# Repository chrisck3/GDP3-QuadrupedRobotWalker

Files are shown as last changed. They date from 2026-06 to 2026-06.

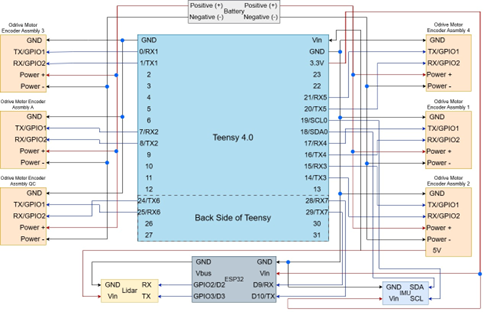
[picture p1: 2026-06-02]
Electronics Architecture/teensy_odrive_ASSY.png

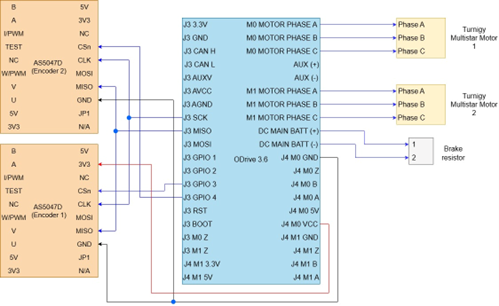
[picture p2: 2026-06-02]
Electronics Architecture/odrive_ASSY.png

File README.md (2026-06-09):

# MORPH — Modular Quadrupedal Robot Platform

**FEEG6013 Group Design Project, University of Southampton, 2025/26**

MORPH is an open-source quadrupedal robot built as a research and inspection platform. This repository hosts the full design package for the project: CAD, mechanical and electrical documentation, firmware for both the on-board controller and the wireless controller, the gait-generation GUI, and the supporting test and calibration material.

This year's project did not start from scratch. The mechanical chassis and the original Teensy gait code were inherited from a previous group's GDP. When we picked it up, the platform was not running. The aim for this iteration was to reactivate it, identify where it was falling short for real research and inspection use, and design, manufacture, and test the upgrades that would make it a credible open-source alternative to the commercial quadrupeds.

The robot now walks reliably on flat ground and slopes up to 12.5 degrees, stays statically stable up to 30 degrees, detects obstacles with LiDAR and stops before hitting them, and is driven from a phone over WiFi. What we did not finish, and what would be sensible next steps, is documented.

Although our robot is called MORPH, it should have been called Murphy, after the Murphy's Law. As the Murphy's law state, "Anything that can go wrong will go wrong", and with our robot that was definitely true during testing days!

<p align="center">
  
</p>


## What's new in this iteration

The mechanical core is iterated rather than rebuilt. The electronics, sensing, control, and software stack are mostly new. A short summary of the changes:

**Mechanical**

* Topology-optimised PLA leg structures (40% infill), validated by FEA, replacing the original plywood legs that were responsible for over 5% positional error.
* Custom AS40 silicone feet, cast in-house, with a measured static friction coefficient of around 1.15 against the design target surfaces.
* Adjustable leg-housing clasp with continuous variable tension, removing the slack and fatigue cracking that the original press-fit clasp suffered from.

**Electronics**

* Bespoke soldered protoboard with JST-XH connectors and header pins. Replaces the inherited breadboard and hot-glued wiring that was failing under vibration.
* BNO055 IMU mounted at the centre of mass for pitch and roll sensing.
* RPLidar A1 M8 mounted on top for 360-degree obstacle detection.
* Arduino Nano ESP32 added alongside the Teensy 4.0 for WiFi communication and to run the LiDAR safety stop loop.

**Software and sensing**

* Browser-based wireless controller served by the ESP32. Replaces the broken Bluetooth module on the inherited platform. MAC whitelist for access control.
* IMU sensor-fusion pipeline using a Kalman filter, plus a Periodic Disturbance Cancellation algorithm to remove the gait-induced body oscillation from the orientation signal. Lets the robot tell true terrain slope apart from its own walking wobble.
* Slope-responsive body levelling. The cleaned IMU pitch and roll are used to adjust individual leg heights so the body stays level on an incline.
* LiDAR cluster-detection algorithm that triggers an automatic stop before an obstacle, with debouncing across full sweeps to avoid twitching.
* Refactored, modular Arduino codebase with calibration tooling, structured to be readable by the next group rather than be a single 1500-line `.ino`.

## Hardware at a glance

|Subsystem|Part|Role|
|-|-|-|
|Main controller|Teensy 4.0|Runs the gait, kinematics, IMU fusion, and ODrive comms.|
|Wireless and safety|Arduino Nano ESP32|WiFi web server, LiDAR polling and obstacle stop.|
|Motor drivers|6x ODrive (v0.5.x)|Drive 12 BLDC motors over UART.|
|Actuation|12x BLDC motors with herringbone and worm-wheel gear reduction|Hip, knee, and shoulder for each of four legs.|
|Inertial sensing|Adafruit BNO055|Body pitch and roll for slope detection.|
|Obstacle sensing|Slamtec RPLidar A1 M8|360-degree 2D scan, drives the auto-stop.|
|Operator interface|Any phone, tablet, or laptop with a browser|Connects to the ESP32's hosted web page over local WiFi.|

Targets the platform was designed to and (within limits) achieved: 19 kg total mass, 5 kg additional payload, 0.25 m/s locomotion speed, 60 mm step length, 10% positional uncertainty benchmarked against the ANYmal platform.

## Getting started

The full assembly, calibration, and bring-up procedure is in repository. 

1. Open the assembly in Solidworks if you want to review or modify the mechanical design.
2. Wire the electronics per the wiring diagram. The protoboard is the central distribution point.
3. Calibrate the six ODrives one at a time using their own tools. The firmware tunes gains and limits on top but assumes the motor configuration is already valid.
4. Flash the Teensy firmware and the ESP32 firmware located on the repo. Each has its own README with the dependencies and bring-up steps.
5. Run the IMU calibration routine once on first power-up. Offsets are saved to EEPROM and reloaded automatically afterwards.
6. On the ESP32 serial monitor, note the printed IP address. Open it in a browser on a whitelisted device and the controller page loads.

## Group members (2025/26)

|Name|Primary contribution areas|
|-|-|
|James Over|Project lead, mechanical design, legs design, ODrive Calibration|
|Antoine Khoury|Mechanical design, Market Analysis, kinematics, ODrive Calibration|
|Nikolas Roussos|Wireless Communication, Software Lead, IMU filtering, Stakeholder Analysis|
|Christos Karayiannis|Mechanical design, foot design and manufacturing, testing|
|Antonin Develay|CAD Lead, Clasp and Leg Design|
|Andreas Savvidis|IMU Lead, lab testing|

## Acknowledgements

* **Dr. Thomas Bull** — primary supervisor, for guidance throughout the project.
* **Prof. Suleiman Sharkh** — co-supervisor, for technical advice on the motor drive and electronics side.
* **Paul Leggett** — for technical support and access to the mechatronics lab.

## Limitations and recommended future work

Some things we did not finish, and a few that we'd genuinely change if doing this again. Worth knowing before you build on the project:

* **Trot gait is not validated.** The trot gait table exists in the firmware and the robot can be made to trot in a controlled setting, but the dynamic stability has not been characterised. The default and tested gait is the crawl.
* **Weight-shift is implemented but disabled.** A separate weight-shift gait table is in `structdef.h` with the gain set to zero. It was never finished or tuned.
* **The Fourier and binned-angle terrain estimators in the IMU code are experimental.** The notch filter is the working production path. The Fourier path is left in for future work and currently uses placeholder coefficients.
* **The mechanical clasp design is improved but not perfect.** Long-duration fatigue testing was not in scope. Inspect periodically.
* **Outdoor LiDAR exposure.** The RPLidar A1 is vulnerable to direct sunlight. A simple optical shield is sketched in CAD but not manufactured.
* **Autonomy is limited to obstacle stopping.** There is no path planning or SLAM. The LiDAR data and ESP32 are capable of running this, and the framework is in place to extend in that direction.

If you take this further, the firmware READMEs are the right place to start.

## License

Open-source for academic and non-commercial use.

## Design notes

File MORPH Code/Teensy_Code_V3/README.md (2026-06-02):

# MQRPII Quadruped Firmware (Teensy 4.0)

Firmware for a four-legged walking robot, running on a Teensy 4.0. It drives 12 motors through six ODrive controllers, walks under WiFi command, and uses a BNO055 IMU to keep the body level on sloped ground.

This was part of a Group Design Project at the University of Southampton. I'm putting it up open-source so the next person who picks up a quadruped like this doesn't have to start from scratch. The code works and the robot walks, but it is research firmware, not a polished product. There are bits that are tuned and proven on the rig, and bits that are still placeholders waiting for someone to finish them. We've tried to be honest about which is which throughout, both here and in the comments.

## What it does

* Walks forward, backward, left, right, and yaws on the spot, commanded over WiFi.
* Converts foot position targets into ODrive encoder commands through a closed-form 2-link inverse kinematic model.
* Reads body pitch and roll from a BNO055 (Kalman-filtered) and adjusts individual leg heights so the body stays level on a slope.
* Stops on command, including a zero-packet stop intended for a LiDAR obstacle trigger.

The default gait is a 16-phase crawl (one leg at a time). A trot gait is included in the source but commented out, with instructions for switching.

## Hardware

| Teensy 4.0 : Main controller. Uses six hardware serial ports (Serial1-Serial6) for the ODrives and Serial7 for WiFi. |
| 6x ODrive (v0.5.x):| Driven over ASCII UART at 115200 baud. Four control a leg each (hip + knee); two are shoulder drives that each serve two legs. |
| 12x BLDC motors : Two per leg (hip, knee) plus shoulder abduction. |
| BNO055 IMU : On I2C (address 0x28). Used for slope detection. |
| ESP (WiFi link) : Sends the 3-value control packet to the Teensy. |

### Leg and ODrive mapping

The leg index convention is used everywhere in the code, so it's worth stating up front:

```
0 = FR (front right)
1 = BL (back left)
2 = FL (front left)
3 = BR (back right)
```

The mapping lives in `pos\_est()` and `actuate()` in `odrv\_rw\_functions.ino`. If you rewire anything, that is the single place you have to get right, or a leg will move on the wrong axis.

## Code structure

This is an Arduino multi-tab sketch. All the `.ino` files compile together as one program alongside the main `Teensy\_Code\_V2\_9\_4.ino`.

|File|What's in it|
|-|-|
|`Teensy\_Code\_V2\_9\_4.ino`|Main sketch. Setup, the WiFi packet state machine, the command mapping, and the main gait loop.|
|`structdef.h`|The gait tables. Pre-computed foot trajectories for the crawl gait (and a commented-out trot gait), phase by phase.|
|`matrix\_kinematics.ino`|Inverse kinematics. Turns x/y/z foot targets into ODrive encoder turns. Also builds the per-phase gait matrix in `create\_mat()`.|
|`odrv\_rw\_functions.ino`|Higher-level ODrive routines: set state, set input mode, read positions, actuate all 12 axes, push tuning gains.|
|`odrv\_dual\_axis\_ctrl\_Func.ino`|Low-level ODrive ASCII command wrappers (read/write a single axis).|
|`wifi\_func.ino`|Builds and sends the framed response packet back to the ESP.|
|`imu\_func.ino`|BNO055 setup and the per-loop IMU read, Kalman filtering, axis remapping, and gait-wobble removal.|
|`imu\_notch\_filter.ino`|Cascaded IIR notch filters that strip the gait oscillation out of the IMU signal so only real terrain tilt is left.|
|`imu\_calibration.h` / `.cpp`|Save and restore BNO055 calibration offsets to EEPROM.|
|`body\_level.ino`|Takes the cleaned terrain pitch/roll and works out how much to raise or lower each leg to keep the body level.|

## How it works

### Walking

The robot walks by stepping through a fixed table of foot positions (`structdef.h`). Each of the 16 phases gives every foot a target offset, made up of a vertical lift arc plus forward/back, lateral, and yaw components. The WiFi command scales those components: forward speed scales the FB table, strafe scales LR, turning scales RT. `create\_mat()` sums them, `kinematics\_mat()` converts the result to encoder positions, and an interpolation step ramps the motors smoothly between phases.

A phase only advances once all 12 interpolations have finished, so the gait timing follows the slowest joint rather than a fixed clock. The loop timer also scales with commanded speed, so a faster command means a faster cycle.

### Staying level on a slope

The IMU gives body pitch and roll, but walking itself rocks the body, so the raw signal is a mix of real slope and self-induced wobble. The firmware deals with this in two stages. `imu\_notch\_filter.ino` notches out the gait frequency and its second harmonic, leaving a cleaner terrain estimate. `body\_level.ino` then converts that pitch and roll into a height correction for each foot and feeds it into `hleg\[]`, the per-leg standing height the kinematics uses.

The slope correction is an integrator with memory, not a simple proportional adjustment. The reasoning behind that (and why a naive version caused the body to snap back and oscillate) is written out in the header comment of `body\_level.ino`. If you're going to touch the levelling, read that first.

### Communication

The ESP sends an 8-byte frame: `0xAA 0x55` header, six payload bytes (three big-endian int16 values), and a one-byte checksum. The Teensy parses it with a small state machine in the main loop, maps the three values to movement commands, and sends a framed acknowledgement back. An all-zero packet is treated as a stop, which is how the LiDAR obstacle trigger is meant to halt the robot.

## Getting it running

1. Install the Arduino IDE, and the libraries below (The RPLiDAR library is slightly modified).
2. Wire the six ODrives to Serial1-Serial6 and the WiFi module to Serial7. Check the leg mapping in `odrv\_rw\_functions.ino` matches your wiring.
3. Calibrate and tune your ODrives first using ODrive's own tools. This firmware assumes the motors are already configured and only pushes gains and limits on top.
4. Open `Teensy\_Code\_V2\_9\_4.ino` (it pulls in the other tabs automatically) and flash it.
5. On the first run, watch the serial monitor at startup. It prints the initial leg positions and flags an offset error if any axis reads zero, which usually means an ODrive isn't responding.

### Dependencies

* `ODriveUART` (ODrive v0.5.x ASCII interface)
* `Adafruit\_BNO055` and `Adafruit\_Sensor`
* `Kalman` by TKJ Electronics (https://github.com/TKJElectronics/KalmanFilter)
* `Ramp`
* `SerialTransfer`

## Things to know before you trust it

I'd rather you hit these in the README than discover them mid-test:

* **The IMU mounting offsets are hand-measured.** The trim values in `imu\_func.ino` correct for how the BNO055 sits on this chassis. On a different build they will be wrong. If the robot thinks it's tilted while sitting on a flat floor, that's the first thing to adjust.
* **The gait-wobble compensation is not finished.** The notch filter is the working path for removing wobble; the Fourier and bin methods are earlier experiments left in for reference. Don't expect the Fourier terrain estimate to mean anything until those coefficients are fitted to real logged data. The how-to-tune notes are in the comments.
* **`actuate2()` uses hardcoded encoder positions.** These are the measured home positions for this specific robot, found by hand which are 1/4 turn from the legs compressed limits. They are not general. If your assembly differs, these numbers will send the legs to the wrong place.
* **ODrive input mode numbers.** The code sets input mode 5 for trajectory control. Note that the surrounding comments occasionally call this TRAP\_TRAJ; check the mode against your ODrive firmware version, as the numbering matters and the comment may not match.

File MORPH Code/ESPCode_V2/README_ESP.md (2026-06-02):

# MQRPII ESP32 Controller and LiDAR Safety Stop

## What it does

- Hosts an HTTP server on the local WiFi network that serves a phone-friendly directional control page (forward, back, left, right, stop).
- Translates button presses into 8-byte binary packets and sends them to the Teensy over a UART link.
- Listens for the Teensy's acknowledgement packets on the same link and prints them to the serial monitor (for debugging).
- Polls an RPLidar continuously, runs a cluster-detection algorithm on the points, and overrides any forward command with a STOP if it sees an obstacle in the danger zone.
- Locks the controller to a MAC address whitelist so a random device on the same WiFi can't drive the robot.

## Hardware

| Part | Notes |
|---|---|
| Arduino Nano ESP32 | The main controller. Uses Serial1 for the LiDAR, Serial2 for the Teensy, USB Serial for the debug monitor. |
| RPLidar A1 | 360-degree 2D LiDAR. Mounted on top of the robot pointing forward. The 0-degree angle direction matters and is set by the physical mount. |
| Teensy 4.0  | Receives the binary motion command and runs the gait. |
| Phone, tablet, or laptop | Anything with a browser on the same WiFi network. |

### Pin map

```
ESP32 pin    Function
---------    --------
RX1 / 2      LiDAR RX
TX1 / 3      LiDAR TX
RX2 / 10     Teensy TX (data into ESP)
TX2 / 9      Teensy RX (data out to robot)
GPIO 8       Status LED
```

Both UARTs run at 115200 baud, 8N1.

## Communication protocol

The ESP and the Teensy exchange the same framed packet in both directions:

```
[0xAA] [0x55] [b0 b1] [b2 b3] [b4 b5] [checksum]
 hdr1   hdr2  int16_1  int16_2  int16_3   sum of 6 payload bytes
```

Three signed 16-bit integers packed big-endian, with a one-byte additive checksum over the payload. Same format both ways, so the parser code is symmetric.

The three values from the ESP are direction flags A, B, C with this encoding:

| Command | A | B | C |
|---|---|---|---|
| FORWARDS  | 1 | 0 | 0 |
| LEFT | 0 | 1 | 0 |
| RIGHT | 0 | 0 | 1 |
| BACKWARDS | 1 | 1 | 1 |
| STOP | 0 | 0 | 0 |

A zero packet is the stop command. The Teensy treats it as both "stand still" and "the LiDAR has just tripped", so it's safe to repeat.

## How it works

### Web UI and command flow

When a client connects, the ESP looks up its MAC by querying its own ARP table for the client's IP. If the MAC isn't on the whitelist, the connection is dropped. If it is, the ESP serves a single-page HTML controller with five buttons. Each button is a normal HTTP GET to a URL like `/FORWARDS`, which the ESP parses, converts to the right A/B/C flag triple, and sends to the Teensy as a binary packet.

The page is plain HTML/CSS with no JavaScript. It re-renders after each command so the displayed state always matches what was last sent. That keeps it usable from any browser and avoids needing to fight with WebSockets on the ESP.

### LiDAR obstacle detection

The LiDAR streams individual range-and-angle measurements as fast as the loop can read them. The obstacle logic does three things:

1. **Filter by distance and angle.** A point counts as a "hit" if its distance is in the danger zone for its angle. The front sector (45 to 135 degrees) uses a tighter cutoff than the sides, because forward motion is the only direction this is really protecting against. Points closer than `THRESHOLD_MM` are ignored — those are reflections from the robot's own body.

2. **Cluster the hits.** A single noisy reading shouldn't stop the robot. The algorithm counts consecutive hits and only triggers if the cluster is wide enough. A short gap of empty readings inside a cluster (up to `MAX_GAP`) is absorbed back in, because partially reflective objects show up as broken cluster.

3. **Scale the cluster size to distance.** A real-world object covers fewer LiDAR samples when it's far away than when it's close. `minPoints` is recomputed at the start of each cluster from the actual hit distance, so a small object close-up triggers a stop just as reliably as a larger one farther away. The formula assumes the LiDAR gives roughly one point per 1.3 degrees and targets a 100 mm-wide object.

4. **Debounce across full rotations.** The `startBit` flag from the LiDAR marks the start of a new 360-degree sweep. The stop stays latched until a full sweep completes *without* re-detecting the obstacle. This stops the robot from twitching between "stop" and "go" if a measurement flickers.

When the stop triggers, the ESP immediately sends a STOP packet to the Teensy. Only the FORWARDS button is gated by the LiDAR — LEFT, RIGHT, BACKWARDS, and STOP all go through even with the latch set, so the operator can strafe or reverse out of the obstacle.

### Security

There's a MAC whitelist and that's it. Anything on the network whose MAC isn't in `ALLOWED_MACS` gets disconnected before it can issue a command. There's no HTTPS, no login, no token. This is fine for a closed lab network with a known set of devices. It is not safe to expose to a network you don't control.

On the very first request from a new device, the ESP's ARP table sometimes hasn't cached the MAC yet, in which case the lookup returns empty. The default behaviour is to let that request through with a warning. There's a commented line in `loop()` that turns this into a hard reject if you'd rather be strict.

## Getting it running

1. Install the Arduino IDE with the Arduino ESP32 board package (Nano ESP32 selected).
2. Install the libraries below.
3. Wire the LiDAR to Serial1 (pins 2 and 3) and the Teensy to Serial2 (pins 9 and 10). Power the LiDAR from its own supply — the ESP can't source enough current.
4. **Open the sketch and edit the top of the file before flashing:**
   - Set `ssid` and `password` to your WiFi network.
   - Replace the two placeholder MAC addresses in `ALLOWED_MACS[]` with the MACs of the devices you want to allow. Uppercase, colon-separated, e.g. `"A0:B1:C2:D3:E4:F5"`. If you don't know a device's MAC, leave a placeholder in for now, flash the sketch, and watch the serial monitor — the ESP prints every connecting client's MAC on the first hit.
5. Flash and open the serial monitor at 115200. It prints the ESP's own IP address on boot. Open that IP in a browser on a whitelisted device, and the controller page should load.

### Dependencies

- `RPLidar` (https://github.com/robopeak/rplidar_arduino, works with the A1)
- `WiFi.h` (bundled with the ESP32 board package)
- `esp_wifi.h`, `lwip/etharp.h`, `lwip/ip_addr.h` (also bundled — used for the ARP-based MAC lookup)

## Tuning notes

The constants near the top of the file are the ones worth changing first if behaviour isn't right on your rig:

| Constant | What it controls |
|---|---|
| `STOP_DISTANCE_FRONT_MM` | How close an object in front has to be before a stop triggers. |
| `STOP_DISTANCE_SIDE_MM`  | Same, for objects to the sides and rear. |
| `THRESHOLD_MM` | Anything closer than this is ignored as a self-reflection. Set it to just outside the LiDAR's view of your own chassis. |
| `MAX_GAP` | How many empty readings inside a cluster get tolerated. Higher means more permissive — useful for shiny or dark obstacles, but raises false-positive risk. |
| The `100.0f` in the `minPoints` formula | Target object width in mm. Make this smaller if you want to detect thinner obstacles, larger if you're getting false stops from clutter. |
| The `1.3f` in the same formula | Approximate degrees-per-sample of the LiDAR. Should be close enough for the A1; verify if you're using a different scanner. |

## Things to know before you trust it

- **The LiDAR angle origin depends on how the LiDAR is mounted.** The angle ranges in `getStopDistance()` assume 0 degrees points forward. If you bolt the LiDAR on rotated 90 degrees, the front quadrant won't be the front any more. The serial monitor prints the angle of any detected object, which is the fastest way to check.
- **The MAC whitelist will be empty as shipped.** The two MACs in the repo are placeholders. Without editing them, no device can connect.
- **The WiFi credentials are in plaintext.** Don't push the sketch back up to a public repo with your real SSID and password baked in.
- **First-connection MAC lookup can fail.** As described above, a brand new device can sneak through the first request. If that matters in your setup, switch to strict mode.
- **The Teensy acknowledgement is not used for control.** The RX state machine is there for debugging the serial link. If you build a closed-loop control flow that needs the robot's state, you'll need to extend `pollSerial2RX()` to do something with `r1`, `r2`, `r3` beyond printing them.

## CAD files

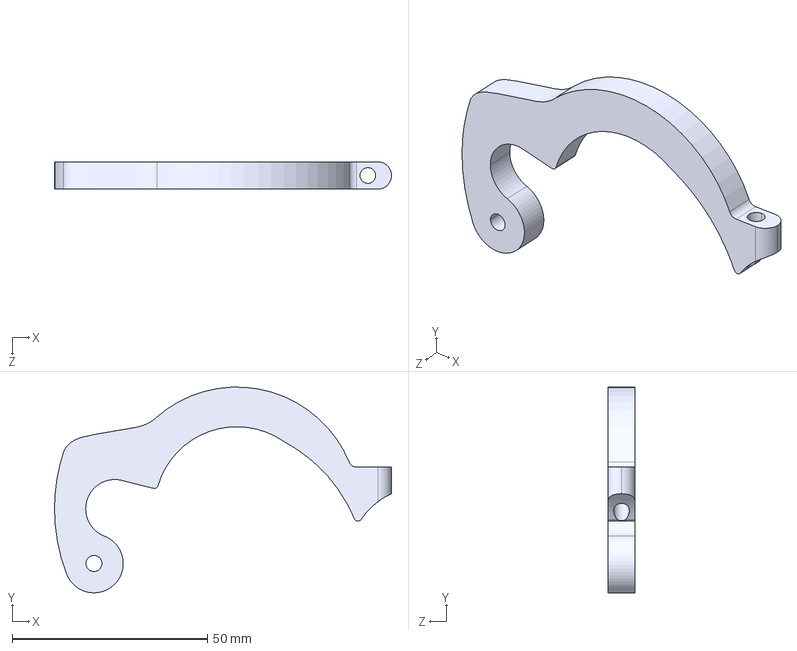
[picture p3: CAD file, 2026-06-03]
CAD/Clasp/Clasplower.STEP
86.2 x 52.6 x 7.00 mm

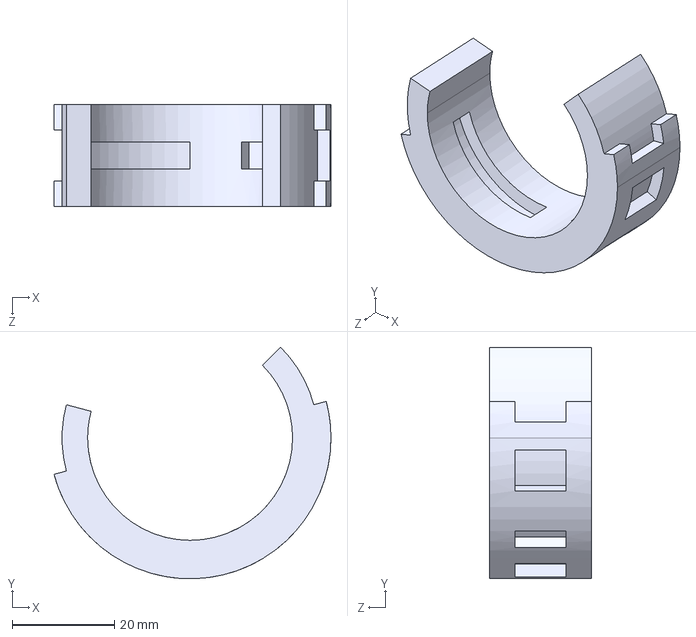
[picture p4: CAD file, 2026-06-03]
CAD/Feet/Footclip.STEP
54.1 x 45.2 x 20.0 mm

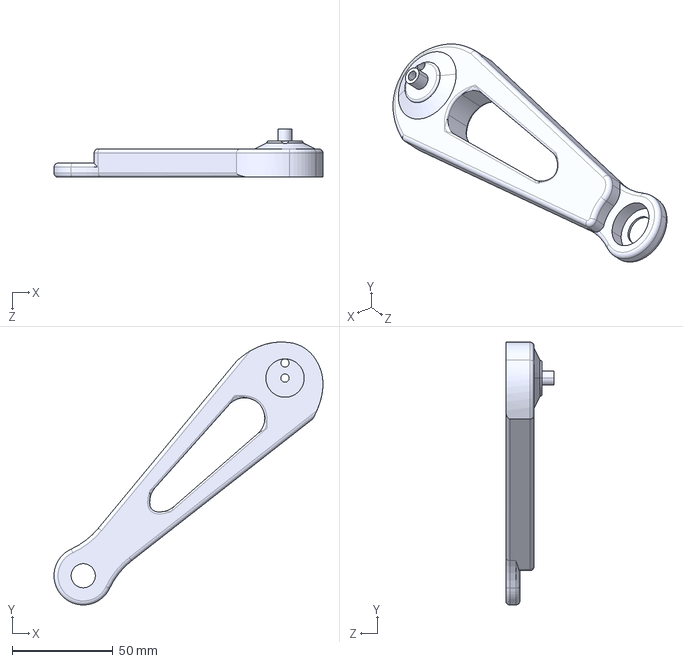
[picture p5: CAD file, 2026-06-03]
CAD/Legs/ShinShort.STEP
133.3 x 130.3 x 24.0 mm

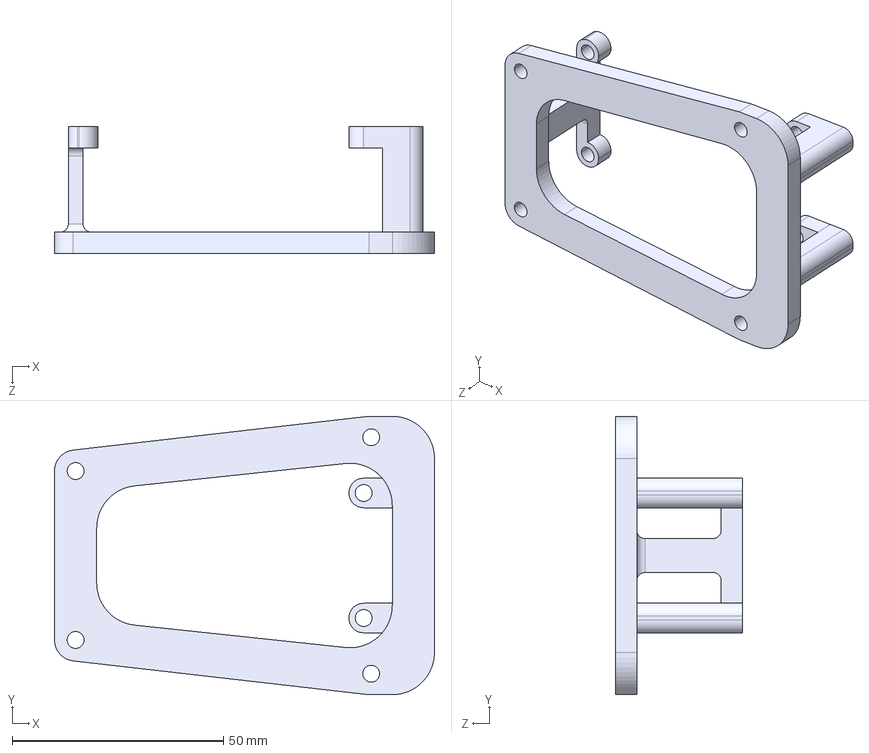
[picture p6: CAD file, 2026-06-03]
CAD/Lidar + Protoboard/LidarStand.STEP
90.0 x 65.9 x 30.0 mm

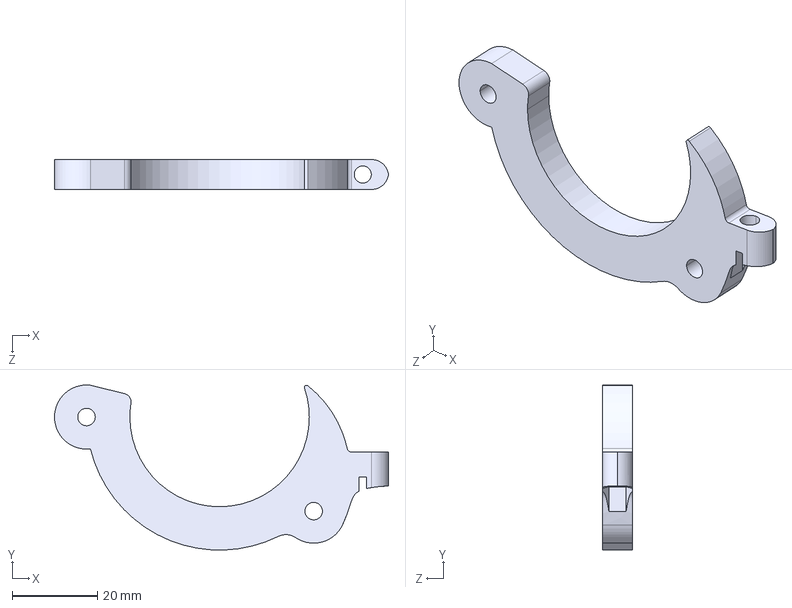
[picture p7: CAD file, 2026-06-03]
CAD/Clasp/Claspupper.STEP
78.2 x 38.6 x 7.00 mm

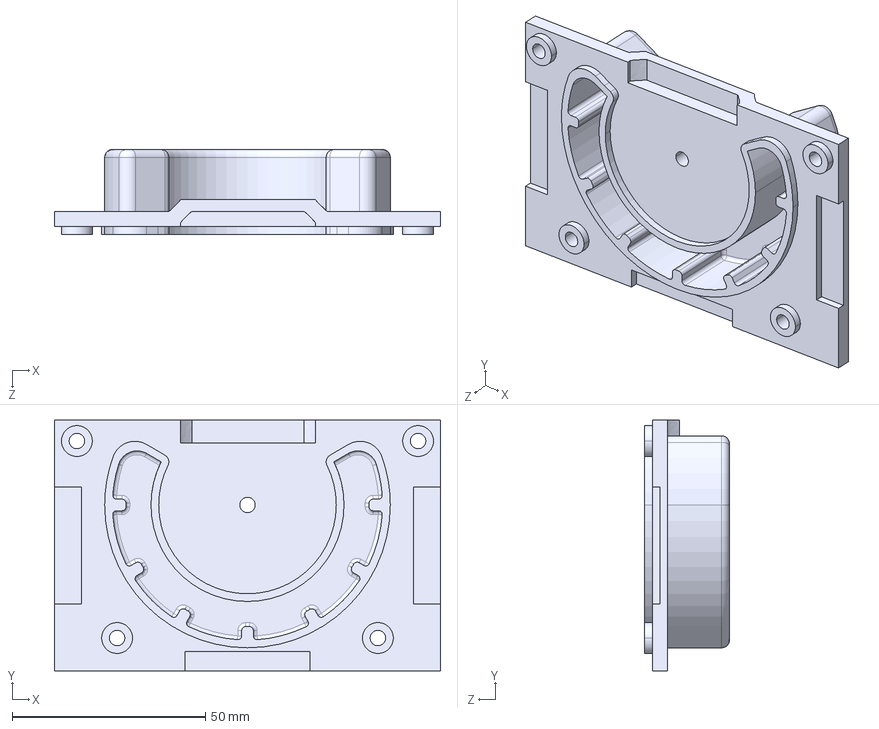
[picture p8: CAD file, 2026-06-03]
CAD/Feet/Mould1.STEP
100.0 x 65.0 x 22.0 mm

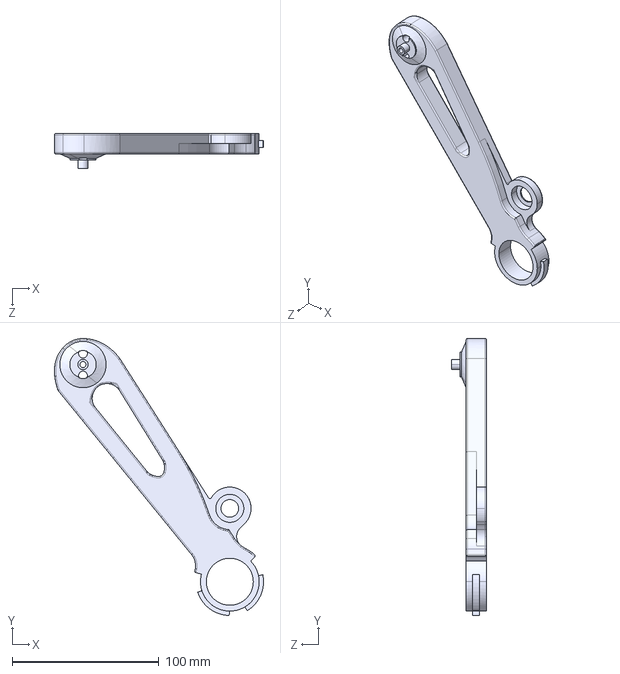
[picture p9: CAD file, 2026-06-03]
CAD/Legs/ShinLong.STEP
142.5 x 188.7 x 24.0 mm

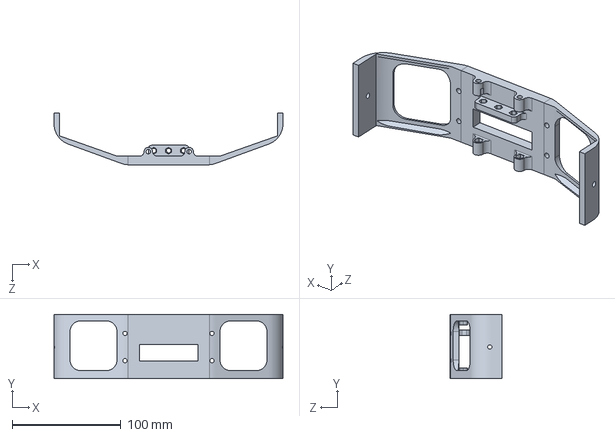
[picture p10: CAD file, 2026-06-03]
CAD/Lidar + Protoboard/Protoboard.SLDPRT
210.6 x 59.2 x 47.4 mm

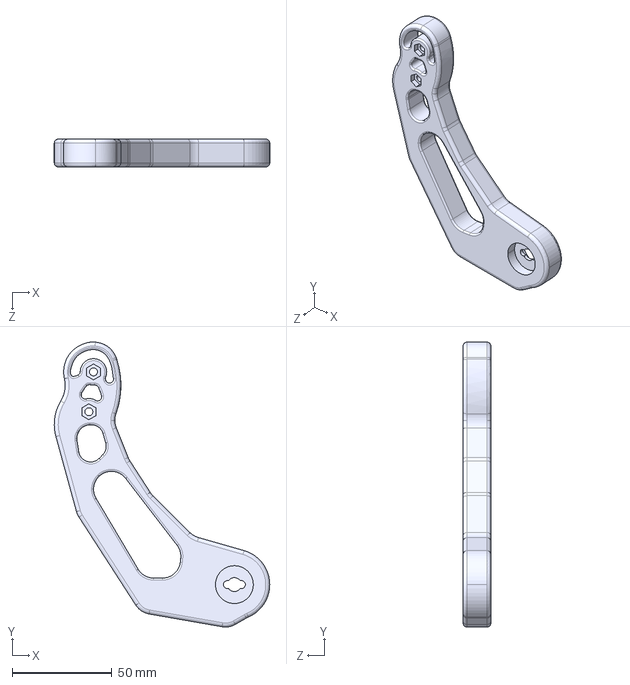
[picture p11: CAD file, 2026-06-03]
CAD/Legs/Thigh.STEP
108.3 x 143.2 x 14.0 mm

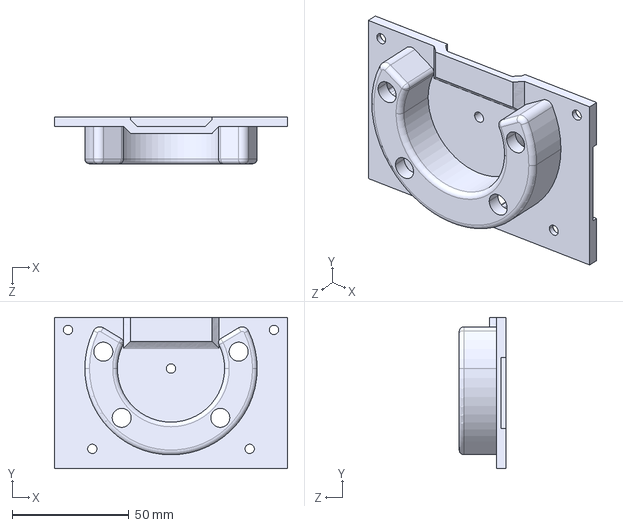
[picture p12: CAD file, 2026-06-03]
CAD/Feet/Mould2.STEP
100.0 x 65.0 x 20.0 mm

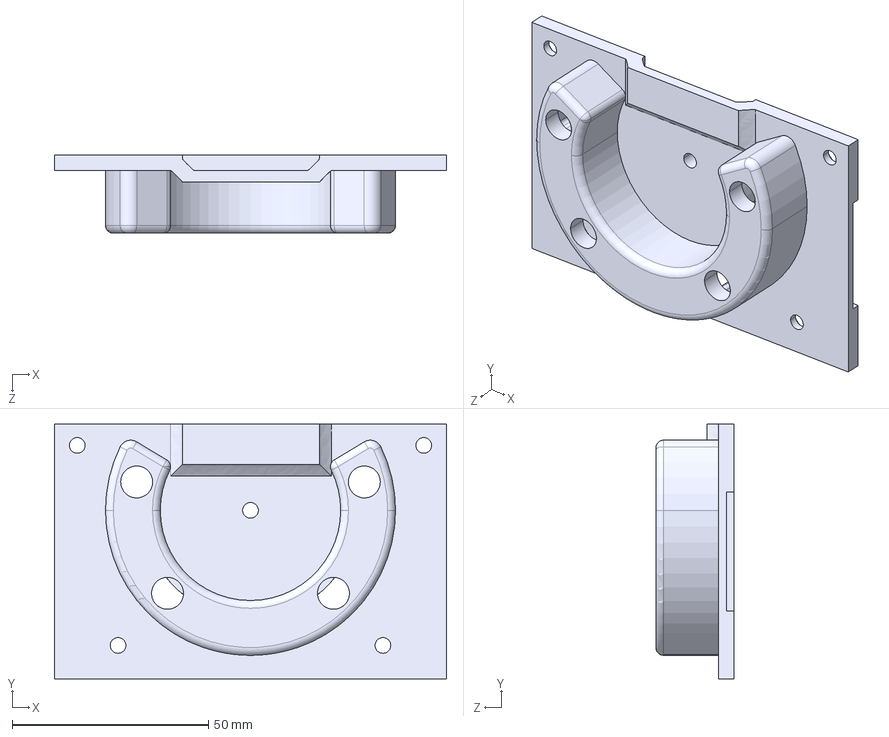
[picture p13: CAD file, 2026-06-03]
CAD/Feet/Mouldbottom.STEP
100.0 x 65.0 x 20.0 mm

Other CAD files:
CAD/Feet/Mouldtop.STEP
CAD/Clasp/Clasplower.SLDPRT
CAD/Clasp/Claspupper.SLDPRT
CAD/Feet/Footclip.SLDPRT
CAD/Feet/Mould1.SLDPRT
CAD/Feet/Mould2.SLDPRT
CAD/Feet/Mouldbottom.SLDPRT
CAD/Feet/Mouldtop.SLDPRT
CAD/Legs/ShinLong.SLDPRT
CAD/Legs/ShinShort.SLDPRT
CAD/Legs/Thigh.SLDPRT
CAD/Lidar + Protoboard/LidarStand.SLDPRT

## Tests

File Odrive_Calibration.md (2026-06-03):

# ODrive Calibration

Using the Python ODrive library ([odrivetool](https://docs.odriverobotics.com/v/0.5.6/getting-started.html))

> **Recommended:** Calibrate each driver individually on a PSU.

---

## Useful Commands

### Factory Reset

```python
odrv0.erase_configuration()
```

### Check Bus Voltage

```python
odrv0.vbus_voltage
```

### Error Handling

```python
dump_errors(odrv0)
```

```python
odrv0.clear_errors()
```

### Check Axis State

> `0` = No state, `1` = Idle, `8` = Closed loop

```python
odrv0.axis0.current_state
```

### Check Input Mode

> `5` = Trapezoidal trajectory

```python
odrv0.axis0.controller.config.input_mode
```

### Backup & Restore Configuration

```python
# Save config to file
odrivetool backup-config my_config.json
```

```python
# Restore config from file
odrivetool restore-config my_config.json
```

---

## Motor Calibration

Both a **configuration** and **anti-cogging** calibration should be saved to the ODrive for a reliable and accurate setup.

---

### Turnigy 100 kV — Configuration

#### 1. Current & Velocity Limits

```python
odrv0.axis0.motor.config.current_lim = 40
odrv0.axis0.controller.config.vel_limit = 5

odrv0.axis1.motor.config.current_lim = 40
odrv0.axis1.controller.config.vel_limit = 5
```

#### 2. Brake Resistor

> Only required for firmware **0.5.5** and **0.5.6** — remove this line for other versions.

```python
odrv0.config.enable_brake_resistor = True
```

```python
odrv0.config.brake_resistance = 2
odrv0.config.dc_bus_overvoltage_trip_level = 26
```

#### 3. Motor Configuration

```python
odrv0.axis0.motor.config.motor_type = 0
odrv0.axis0.motor.config.pole_pairs = 20
odrv0.axis0.motor.config.torque_constant = 8.27 / 100
odrv0.axis0.motor.config.calibration_current = 20

odrv0.axis1.motor.config.motor_type = 0
odrv0.axis1.motor.config.pole_pairs = 20
odrv0.axis1.motor.config.torque_constant = 8.27 / 100
odrv0.axis1.motor.config.calibration_current = 20
```

#### 4. Encoder Configuration (AS5047D — SPI Mode)

> Set the correct CS GPIO pin for your wiring.

```python
odrv0.axis0.encoder.config.abs_spi_cs_gpio_pin = 8
odrv0.axis0.encoder.config.mode = ENCODER_MODE_SPI_ABS_AMS
odrv0.axis0.encoder.config.cpr = 2**14

odrv0.axis1.encoder.config.abs_spi_cs_gpio_pin = 7
odrv0.axis1.encoder.config.mode = ENCODER_MODE_SPI_ABS_AMS
odrv0.axis1.encoder.config.cpr = 2**14
```

#### 5. Save & Reboot

```python
odrv0.save_configuration()
odrv0.reboot()
```

> **Note:** A full power cycle may be required if encoder positional errors appear.

#### 6. Encoder Offset Calibration (SPI Mode)

> Nothing should physically happen during this step.

```python
odrv0.axis0.requested_state = AXIS_STATE_ENCODER_OFFSET_CALIBRATION
odrv0.axis1.requested_state = AXIS_STATE_ENCODER_OFFSET_CALIBRATION
```

#### 7. Full Calibration Sequence

> The motor should beep and rotate in both directions.

```python
odrv0.axis0.requested_state = AXIS_STATE_FULL_CALIBRATION_SEQUENCE
odrv0.axis1.requested_state = AXIS_STATE_FULL_CALIBRATION_SEQUENCE
```

#### 8. Flag as Pre-Calibrated

> This allows the ODrive to skip full calibration on the next boot and go straight to closed loop.

```python
odrv0.axis0.encoder.config.pre_calibrated = True
odrv0.axis1.encoder.config.pre_calibrated = True

odrv0.axis0.motor.config.pre_calibrated = True
odrv0.axis1.motor.config.pre_calibrated = True
```

#### 9. PNI Control Gains

```python
odrv0.axis0.controller.config.pos_gain = 100
odrv0.axis0.controller.config.vel_gain = 0.3
odrv0.axis0.controller.config.vel_integrator_gain = 0.4

odrv0.axis1.controller.config.pos_gain = 100
odrv0.axis1.controller.config.vel_gain = 0.3
odrv0.axis1.controller.config.vel_integrator_gain = 0.4
```

#### 10. Trajectory Control Limits

```python
odrv0.axis0.trap_traj.config.vel_limit = 5.0
odrv0.axis0.trap_traj.config.accel_limit = 5.0
odrv0.axis0.trap_traj.config.decel_limit = 5.0

odrv0.axis1.trap_traj.config.vel_limit = 5.0
odrv0.axis1.trap_traj.config.accel_limit = 5.0
odrv0.axis1.trap_traj.config.decel_limit = 5.0
```

#### 11. Save & Reboot

```python
odrv0.save_configuration()
odrv0.reboot()
```

> Motors are now ready to use without further calibration.

---

### Surpass C5065 435 kV — Configuration

#### 1. Current & Velocity Limits

```python
odrv0.axis0.motor.config.current_lim = 40
odrv0.axis0.controller.config.vel_limit = 5

odrv0.axis1.motor.config.current_lim = 40
odrv0.axis1.controller.config.vel_limit = 5
```

#### 2. Brake Resistor

> Only required for firmware **0.5.5** and **0.5.6** — remove this line for other versions.

```python
odrv0.config.enable_brake_resistor = True
```

```python
odrv0.config.brake_resistance = 2
odrv0.config.dc_bus_overvoltage_trip_level = 25
```

#### 3. Motor Configuration

```python
odrv0.axis0.motor.config.motor_type = 0
odrv0.axis0.motor.config.pole_pairs = 7
odrv0.axis0.motor.config.torque_constant = 8.27 / 435
odrv0.axis0.motor.config.calibration_current = 20

odrv0.axis1.motor.config.motor_type = 0
odrv0.axis1.motor.config.pole_pairs = 7
odrv0.axis1.motor.config.torque_constant = 8.27 / 435
odrv0.axis1.motor.config.calibration_current = 20
```

#### 4. Encoder Configuration (AS5047D — SPI Mode)

> Set the correct CS GPIO pin for your wiring.

```python
odrv0.axis0.encoder.config.abs_spi_cs_gpio_pin = 8
odrv0.axis0.encoder.config.mode = ENCODER_MODE_SPI_ABS_AMS
odrv0.axis0.encoder.config.cpr = 2**14

odrv0.axis1.encoder.config.abs_spi_cs_gpio_pin = 7
odrv0.axis1.encoder.config.mode = ENCODER_MODE_SPI_ABS_AMS
odrv0.axis1.encoder.config.cpr = 2**14
```

#### 5. Save & Reboot

```python
odrv0.save_configuration()
odrv0.reboot()
```

> **Note:** A full power cycle may be required if encoder positional errors appear.

#### 6. Encoder Offset Calibration (SPI Mode)

> Nothing should physically happen during this step.

```python
odrv0.axis0.requested_state = AXIS_STATE_ENCODER_OFFSET_CALIBRATION
odrv0.axis1.requested_state = AXIS_STATE_ENCODER_OFFSET_CALIBRATION
```

#### 7. Full Calibration Sequence

> The motor should beep and rotate in both directions.

```python
odrv0.axis0.requested_state = AXIS_STATE_FULL_CALIBRATION_SEQUENCE
odrv0.axis1.requested_state = AXIS_STATE_FULL_CALIBRATION_SEQUENCE
```

#### 8. Flag as Pre-Calibrated

```python
odrv0.axis0.encoder.config.pre_calibrated = True
odrv0.axis1.encoder.config.pre_calibrated = True

odrv0.axis0.motor.config.pre_calibrated = True
odrv0.axis1.motor.config.pre_calibrated = True
```

#### 9. PNI Control Gains

```python
odrv0.axis0.controller.config.pos_gain = 40
odrv0.axis0.controller.config.vel_gain = 0.125
odrv0.axis0.controller.config.vel_integrator_gain = 0.2

odrv0.axis1.controller.config.pos_gain = 40
odrv0.axis1.controller.config.vel_gain = 0.125
odrv0.axis1.controller.config.vel_integrator_gain = 0.2
```

#### 10. Trajectory Control Limits

```python
odrv0.axis0.trap_traj.config.vel_limit = 5.0
odrv0.axis0.trap_traj.config.accel_limit = 5.0
odrv0.axis0.trap_traj.config.decel_limit = 5.0

odrv0.axis1.trap_traj.config.vel_limit = 5.0
odrv0.axis1.trap_traj.config.accel_limit = 5.0
odrv0.axis1.trap_traj.config.decel_limit = 5.0
```

#### 11. Save & Reboot

```python
odrv0.save_configuration()
odrv0.reboot()
```

> Motors are now ready to use without further calibration.

---

## Anti-Cogging Calibration

> Anti-cogging takes approximately **20 minutes** by default (3600 steps). Run for both axes.

#### 1. Start Anti-Cogging Calibration

```python
# Axis 0
odrv0.axis0.controller.config.control_mode = CONTROL_MODE_POSITION_CONTROL
odrv0.axis0.requested_state = AXIS_STATE_CLOSED_LOOP_CONTROL
odrv0.axis0.controller.config.anticogging.pre_calibrated = False
odrv0.axis0.controller.start_anticogging_calibration()

# Axis 1
odrv0.axis1.controller.config.control_mode = CONTROL_MODE_POSITION_CONTROL
odrv0.axis1.requested_state = AXIS_STATE_CLOSED_LOOP_CONTROL
odrv0.axis1.controller.config.anticogging.pre_calibrated = False
odrv0.axis1.controller.start_anticogging_calibration()
```

#### 2. Monitor Progress

> Poll these flags to track calibration status.
>
> **`calib_anticogging`**: `True` = calibration running, `False` = finished (or not started)  
> **`anticogging_valid`**: `False` = no valid map yet, `True` = map complete and valid

```python
odrv0.axis0.controller.config.anticogging.calib_anticogging
odrv0.axis0.controller.anticogging_valid
```

```python
odrv0.axis1.controller.config.anticogging.calib_anticogging
odrv0.axis1.controller.anticogging_valid
```

> Check the current step index — if it's increasing, calibration is actively running.
> If it returns `0`, calibration may have finished or an error occurred — run `dump_errors` to check.

```python
odrv0.axis0.controller.config.anticogging.index
```

```python
odrv0.axis1.controller.config.anticogging.index
```

#### 3. Finalise Anti-Cogging

> Run this once `anticogging_valid == True` or `calib_anticogging == False`.

```python
# Axis 0
odrv0.axis0.controller.config.anticogging.pre_calibrated = True
odrv0.axis0.controller.config.anticogging.anticogging_enabled = True
odrv0.axis0.requested_state = AXIS_STATE_IDLE

# Axis 1
odrv0.axis1.controller.config.anticogging.anticogging_enabled = True
odrv0.axis1.controller.config.anticogging.pre_calibrated = True
odrv0.axis1.requested_state = AXIS_STATE_IDLE
```

> `save_configuration()` may return `False` if the axis is not in IDLE — ensure both axes are idle before saving.

```python
odrv0.save_configuration()
odrv0.reboot()
```

---

## Running the Motors

#### 1. Verify Calibration (Optional)

```python
odrv0.axis0.motor.is_calibrated    # Expected: True
odrv0.axis0.encoder.is_ready       # Expected: True
```

```python
odrv0.axis1.motor.is_calibrated    # Expected: True
odrv0.axis1.encoder.is_ready       # Expected: True
```

#### 2. Check Absolute Position

> Used to find the absolute position and place legs correctly on start-up.

```python
odrv0.axis0.encoder.pos_estimate
```

```python
odrv0.axis1.encoder.pos_estimate
```

#### 3. Enter Closed Loop & Trapezoidal Trajectory Mode

```python
odrv0.axis0.requested_state = AXIS_STATE_CLOSED_LOOP_CONTROL
odrv0.axis1.requested_state = AXIS_STATE_CLOSED_LOOP_CONTROL

odrv0.axis0.controller.config.input_mode = INPUT_MODE_TRAP_TRAJ
odrv0.axis1.controller.config.input_mode = INPUT_MODE_TRAP_TRAJ
```

#### 4. Set Target Position

> These are **absolute positions**, not relative movements.

```python
odrv0.axis0.controller.input_pos = 1
odrv0.axis1.controller.input_pos = 1
```

```python
# Return to zero
odrv0.axis0.controller.input_pos = 0
odrv0.axis1.controller.input_pos = 0
```

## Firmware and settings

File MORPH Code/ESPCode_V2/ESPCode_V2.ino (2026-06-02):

// ESP32 — WiFi controller and LiDAR safety stop for the MQRPII quadruped.
//
// Talks to the Teensy over Serial2 (binary framed packets, same protocol both ways).
// Hosts a web page so a phone on the same network can drive the robot with
// directional buttons. Polls an RPLidar in the background, and overrides any
// movement command with a STOP if it sees an obstacle inside a danger zone.

#include <Arduino.h>
#include <RPLidar.h>
#include <WiFi.h>
#include "esp_wifi.h"
#include "lwip/etharp.h"
#include "lwip/ip_addr.h"

const char *ssid = "University of Southampton Guest";
const char *password = "Password123";

// -------- SECURITY -----------
// The web UI has no password. The only thing stopping a random device on the
// same WiFi network from driving the robot is a MAC address whitelist.
// Anything not in ALLOWED_MACS gets dropped after the IP-to-MAC lookup.
//
// IMPORTANT before flashing:
//   1. Put your own SSID and password above (these are checked into the repo
//      as placeholders, do not assume they will work on your network).
//   2. Replace the two placeholder MAC addresses below with the MACs of the
//      phones or laptops that should be allowed to control the robot.
//      Uppercase, colon-separated, e.g. "A0:B1:C2:D3:E4:F5".
//   3. If you cannot find a device's MAC, the loop() prints it on the serial
//      monitor the first time that device hits the page.
const char* ALLOWED_MACS[] = {
  "11:22:33:44:55:66", // Placeholder — replace before deployment
  "AA:BB:CC:DD:EE:FF"  // Placeholder — replace before deployment
};
const int NUM_ALLOWED_MACS = sizeof(ALLOWED_MACS) / sizeof(ALLOWED_MACS[0]);

// Teensy serial link (Serial2)
constexpr int TEENSY_RX = 10;
constexpr int TEENSY_TX = 9;
constexpr uint32_t TEENSY_BAUD = 115200;

// LiDAR UART (Serial1)
constexpr int LIDAR_RX_PIN = 2;
constexpr int LIDAR_TX_PIN = 3;
constexpr uint32_t LIDAR_BAUD = 115200;
constexpr int LED_PIN = 8;

// LiDAR obstacle detection constants.
//
// The robot stops if it sees a cluster of LiDAR points closer than these
// distances. Front is checked at a tighter threshold than the sides because
// forward motion is the only direction the LiDAR is really protecting against.
// THRESHOLD_MM is the inner cutoff that ignores readings from the robot's own
// body (the LiDAR sees parts of the chassis at very short range).
// MAX_GAP lets the hit-counter tolerate a few stray empty readings inside a
// real object cluster, so a partially reflective surface still trips a stop.
constexpr int STOP_DISTANCE_FRONT_MM = 450;
constexpr int STOP_DISTANCE_SIDE_MM = 350;
constexpr int MAX_GAP = 4;
constexpr int THRESHOLD_MM = 175;

WiFiServer server(80);
RPLidar lidar;

// Motion state flags (encoding from ESP_lidar_controller_V2)
// FORWARDS:  A=1, B=0, C=0
// LEFT:      A=0, B=1, C=0
// RIGHT:     A=0, B=0, C=1
// BACKWARDS: A=1, B=1, C=1
// STOP:      A=0, B=0, C=0
int wifiFlagA = 0;
int wifiFlagB = 0;
int wifiFlagC = 0;

int hitCount = 0;
int gapCount = 0;
float startAngle = 0.0f;
float avgAngle = 0.0f;
bool stopTriggeredByLidar = false;
bool objectDetectedThisScan = false;
// minPoints: how many consecutive LiDAR hits inside the danger zone count as
// a real object (rather than noise). It depends on distance.
// The formula targets a ~100 mm-wide object at the current distance:
//arc length 100mm at radius dist  ->  angle (rad)  ->  number of LiDAR
//samples assuming the scanner gives ~1 point per 1.3 degrees.
// Initialised here for STOP_DISTANCE_FRONT_MM; recomputed in pollLidar() each
// time a new cluster starts so it matches the actual hit distance.
int minPoints = (int)(100.0f / STOP_DISTANCE_FRONT_MM * 180.0f / (3.1415f * 1.3f));

// Forward declarations
bool isMacAllowed(String clientMac);
// Looks up the MAC of a connected client by reading the ESP32's internal ARP
// table. Returns an empty string if the entry isn't there yet — which happens
// on the very first request from a new device, before the OS has cached it.
// The loop() handles that case by printing a warning instead of blocking.
String getMacFromIp(IPAddress ip);
float getStopDistance(float angle);
void initLidar();
void tryRestartLidar();
void pollLidar();
void sendMotionCommand(int flagA, int flagB, int flagC, const char *label, const char *reason = nullptr);
const char *stateLabel();
void serveControllerPage(WiFiClient &client);

// -------------------- MAC Whitelist Helpers --------------------
bool isMacAllowed(String clientMac) {
  clientMac.toUpperCase();
  for (int i = 0; i < NUM_ALLOWED_MACS; i++) {
    String allowed = String(ALLOWED_MACS[i]);
    allowed.toUpperCase();
    if (clientMac == allowed) return true;
  }
  return false;
}

String getMacFromIp(IPAddress ip) {
  ip4_addr_t ip_addr;
  ip_addr.addr = ip;
  eth_addr *mac_addr = NULL;
  const ip4_addr_t *ip_ptr = &ip_addr;
  ssize_t idx = etharp_find_addr(NULL, ip_ptr, &mac_addr, NULL);
  if (idx >= 0 && mac_addr != NULL) {
    char macStr[18];
    snprintf(macStr, sizeof(macStr), "%02X:%02X:%02X:%02X:%02X:%02X",
             mac_addr->addr[0], mac_addr->addr[1], mac_addr->addr[2],
             mac_addr->addr[3], mac_addr->addr[4], mac_addr->addr[5]);
    return String(macStr);
  }
  return "";
}

// -------------------- Binary packet TX (to Teensy) --------------------
// Sends a framed packet: [0xAA][0x55][6 bytes payload][1 byte checksum]
// Payload: 3 signed 16-bit ints packed big-endian
void sendPacket(int a, int b, int c) {
  uint8_t header[2] = {0xAA, 0x55};
  uint8_t payload[6];
  int16_t vals[3] = { (int16_t)a, (int16_t)b, (int16_t)c };
  for (int i = 0; i < 3; ++i) {
    payload[2*i]   = (uint8_t)((vals[i] >> 8) & 0xFF);
    payload[2*i+1] = (uint8_t)(vals[i] & 0xFF);
  }
  uint8_t sum = 0;
  for (uint8_t byte : payload) sum += byte;
  Serial2.write(header, 2);
  Serial2.write(payload, 6);
  Serial2.write(sum);
}

// -------------------- Binary packet RX (from Teensy) --------------------
// The same framed protocol as the TX side, in reverse. The Teensy echoes
// every command back as an acknowledgement (with the second value negated and
// a sequence counter added to the third), which is what gets printed on the
// serial monitor as "RX OK". Used for debugging the link, not for any control logic
enum RxState { FIND_AA, FIND_55, READ_PAYLOAD, READ_SUM };
RxState rxState = FIND_AA;
uint8_t rxPayload[6];
int rxIdx = 0;

void pollSerial2RX() {
  while (Serial2.available()) {
    uint8_t b = (uint8_t)Serial2.read();
    switch (rxState) {
      case FIND_AA:
        if (b == 0xAA) rxState = FIND_55;
        break;
      case FIND_55:
        rxState = (b == 0x55) ? READ_PAYLOAD : FIND_AA;
        rxIdx = 0;
        break;
      case READ_PAYLOAD:
        rxPayload[rxIdx++] = b;
        if (rxIdx >= 6) rxState = READ_SUM;
        break;
      case READ_SUM: {
        uint8_t sum = 0;
        for (int i = 0; i < 6; ++i) sum += rxPayload[i];
        if (sum == b) {
          int16_t r1 = (int16_t)((rxPayload[0] << 8) | rxPayload[1]);
          int16_t r2 = (int16_t)((rxPayload[2] << 8) | rxPayload[3]);
          int16_t r3 = (int16_t)((rxPayload[4] << 8) | rxPayload[5]);
          Serial.printf("RX OK: r1=%d r2=%d r3=%d\n", r1, r2, r3);
        } else {
          Serial.println("RX checksum mismatch (ESP32)");
        }
        rxState = FIND_AA;
        break;
      }
    }
  }
}

// -------------------- Motion command --------------------
const char *stateLabel() {
  if (wifiFlagA == 1 && wifiFlagB == 1 && wifiFlagC == 1) return "BACKWARDS";
  if (wifiFlagA == 1) return "FORWARDS";
  if (wifiFlagB == 1) return "LEFT";
  if (wifiFlagC == 1) return "RIGHT";
  return "STOP";
}

void sendMotionCommand(int flagA, int flagB, int flagC, const char *label, const char *reason) {
  wifiFlagA = flagA;
  wifiFlagB = flagB;
  wifiFlagC = flagC;
  Serial.print("Command: ");
  Serial.print(label);
  if (reason != nullptr) {
    Serial.print(" (");
    Serial.print(reason);
    Serial.print(")");
  }
  Serial.println();
  sendPacket(flagA, flagB, flagC);
}

// -------------------- LiDAR --------------------
// LiDAR angle ranges
//   45–135°  : front quadrant   -> tighter stop distance
//   135–225° : right side       -> looser stop distance
//   225–315° : back             -> looser (and arguably should be ignored)
//   315–45°  : left side        -> looser
// Returns the cutoff distance for a hit at a given angle.
float getStopDistance(float angle) {
  if (angle >= 45 && angle < 135)   return STOP_DISTANCE_FRONT_MM;
  if (angle >= 135 && angle < 225) return STOP_DISTANCE_SIDE_MM;
  if (angle >= 225 && angle < 315) return STOP_DISTANCE_SIDE_MM;
  return STOP_DISTANCE_SIDE_MM;
}

void initLidar() {
  Serial1.begin(LIDAR_BAUD, SERIAL_8N1, LIDAR_RX_PIN, LIDAR_TX_PIN);
  delay(500);
  if (!lidar.begin(Serial1)) {
    Serial.println("LiDAR init failed");
    return;
  }
  rplidar_response_device_health_t health;
  if (lidar.getHealth(health) == RESULT_OK) {
    Serial.println("LiDAR health OK");
  } else {
    Serial.println("LiDAR health check failed");
  }
  if (lidar.startScan()) {
    Serial.println("LiDAR scan started");
  } else {
    Serial.println("LiDAR scan failed to start");
  }
}

void tryRestartLidar() {
  rplidar_response_device_info_t info;
  if (lidar.getDeviceInfo(info, 100) == RESULT_OK) {
    lidar.startScan();
    Serial.println("LiDAR scan restarted");
  }
}

// One full pass of the obstacle detection. Reads a single point from the
// LiDAR, decides whether it belongs to a cluster of points inside the danger
// zone, and if the cluster is big enough, sends a STOP to the Teensy.
//
// How the cluster detection works:
//   - We count "hits" when points are inside the danger zone.
//   - Stray empty samples inside a real object are tolerated up to MAX_GAP
//     (gapCount) so a slightly reflective surface doesn't break the cluster.
//   - The cluster has to be at least minPoints samples wide to trigger a
//     stop. minPoints scales with distance (farther = fewer samples for the
//     same physical width), so a small object close up trips it just as
//     reliably as a larger one farther away.
//   - startBit marks the start of a new 360° scan. We use it to debounce:
//     stopTriggeredByLidar stays latched until a full scan finishes WITHOUT
//     re-detecting the object, at which point we declare "clear".
void pollLidar() {
  if (lidar.waitPoint() != RESULT_OK) {
    tryRestartLidar();
    Serial.println("Lidar Not Okay");
    return;
  }
  const RPLidarMeasurement &point = lidar.getCurrentPoint();
  const float dist = point.distance;
  const float angle = point.angle;
  const bool startBit = point.startBit;
  const float stopDistance = getStopDistance(angle);

  // Start of a new 360° scan
  if (startBit) {
    Serial.println("Spin");
    if (stopTriggeredByLidar && !objectDetectedThisScan) {
      stopTriggeredByLidar = false;
      Serial.println("LiDAR clear");
    }
    objectDetectedThisScan = false;
  }
  // Point sits inside the danger zone, count it as a hit.
  if (dist > THRESHOLD_MM && dist < stopDistance) {
    Serial.print("H");
    // First hit of a new cluster, record where it started and
    // recompute minPoints for the actual hit distance.
    if (hitCount == 0) {
      startAngle = angle;
      minPoints = (int)(100.0f / dist * 180.0f / (3.1415f * 1.3f));
      if (minPoints < 1) minPoints = 1;
    }
    hitCount++;
    // If we were inside a gap, absorb it into the cluster (gap was a
    // false dropout, not the end of the object).
    if (gapCount > 0) {
      hitCount += gapCount;
      gapCount = 0;
    }
  } else if (hitCount > 0 && gapCount < MAX_GAP) {
    gapCount++;
  } else {
    hitCount = 0;
    gapCount = 0;
  }

  if (hitCount >= minPoints) {
    objectDetectedThisScan = true;
    avgAngle = (angle - startAngle) / 2.0f + startAngle;
    if (!stopTriggeredByLidar) {
      stopTriggeredByLidar = true;
      Serial.print("LiDAR object detected at angle: ");
      Serial.println(avgAngle);
      sendMotionCommand(0, 0, 0, "STOP", "LiDAR");
    }
  }
}

// -------------------- Web UI (from ESP_lidar_controller_V2) --------------------
void serveControllerPage(WiFiClient &client) {
  client.println("HTTP/1.1 200 OK");
  client.println("Content-type:text/html");
  client.println("Connection: close");
  client.println();
  client.println("<!DOCTYPE html><html><head><meta name=\"viewport\" content=\"width=device-width, initial-scale=1\">");
  client.println("<title>ESP LiDAR Controller</title>");
  client.println("<style>");
  client.println(":root{--bg:#f4f0e8;--panel:#fffaf2;--ink:#202020;--accent:#d95f02;--ok:#2f855a;--warn:#c53030;--edge:#d7c7aa;}");
  client.println("*{box-sizing:border-box}body{margin:0;min-height:100vh;display:grid;place-items:center;background:radial-gradient(circle at top,#fffdf7 0,#f4f0e8 45%,#e7dfd0 100%);font-family:Georgia,serif;color:var(--ink);}");
  client.println(".panel{width:min(92vw,440px);padding:28px;border:2px solid var(--edge);border-radius:28px;background:linear-gradient(180deg,var(--panel),#efe4d3);box-shadow:0 18px 40px rgba(54,35,12,.16);}");
  client.println(".title{text-align:center;font-size:2rem;letter-spacing:.08em;margin:0 0 8px}.status{text-align:center;margin:0 0 20px;font-size:1rem}");
  client.println(".status span{font-weight:700}.grid{display:grid;grid-template-columns:repeat(3,1fr);gap:14px;align-items:center}");
  client.println(".btn{display:grid;place-items:center;min-height:92px;border:none;border-radius:22px;text-decoration:none;color:#fff;font-size:2rem;font-weight:700;box-shadow:0 10px 20px rgba(0,0,0,.12), inset 0 2px 0 rgba(255,255,255,.2);}");
  client.println(".btn:active{transform:translateY(2px)}.forward{grid-column:2;background:var(--ok)}.left{grid-column:1;grid-row:2;background:#2b6cb0}.stop{grid-column:2;grid-row:2;background:var(--warn);font-size:1.2rem;letter-spacing:.08em}.right{grid-column:3;grid-row:2;background:#805ad5}.backward{grid-column:2;grid-row:3;background:var(--accent)}");
  client.println(".meta{margin-top:18px;text-align:center;font-size:.95rem;opacity:.82}.blocked{color:var(--warn);font-weight:700}");
  client.println("</style></head><body><div class=\"panel\">");
  client.println("<h1 class=\"title\">Robot Controller</h1>");
  client.print("<p class=\"status\">State: <span>");
  client.print(stateLabel());
  client.println("</span></p>");
  client.println("<div class=\"grid\">");
  client.println("<a href=\"/FORWARDS\" class=\"btn forward\" aria-label=\"FORWARDS\">&#8593;</a>");
  client.println("<a href=\"/LEFT\" class=\"btn left\" aria-label=\"LEFT\">&#8592;</a>");
  client.println("<a href=\"/STOP\" class=\"btn stop\" aria-label=\"STOP\">STOP</a>");
  client.println("<a href=\"/RIGHT\" class=\"btn right\" aria-label=\"RIGHT\">&#8594;</a>");
  client.println("<a href=\"/BACKWARDS\" class=\"btn backward\" aria-label=\"BACKWARDS\">&#8595;</a>");
  client.println("</div>");
  client.print("<p class=\"meta\">LiDAR status: ");
  if (stopTriggeredByLidar) {
    client.print("<span class=\"blocked\">Obstacle detected</span>");
  } else {
    client.print("Clear");
  }
  client.println("</p></div></body></html>");
  client.println();
}

// -------------------- Setup & Loop --------------------
void setup() {
  Serial.begin(115200);
  Serial2.begin(TEENSY_BAUD, SERIAL_8N1, TEENSY_RX, TEENSY_TX);
  pinMode(LED_PIN, OUTPUT);
  digitalWrite(LED_PIN, LOW);
  delay(500);
  initLidar();

  Serial.print("Connecting to ");
  Serial.println(ssid);
  WiFi.begin(ssid, password);
  while (WiFi.status() != WL_CONNECTED) {
    delay(500);
    Serial.print(".");
  }
  Serial.println();
  Serial.println("WiFi connected.");
  Serial.print("IP address: ");
  Serial.println(WiFi.localIP());
  Serial.print("ESP32 MAC: ");
  Serial.println(WiFi.macAddress());
  Serial.println("Waiting for authorized clients...");
  server.begin();
}

void loop() {
  pollSerial2RX();
  pollLidar();

  WiFiClient client = server.available();
  if (!client) return;

  Serial.println("New Client.");

  // ---- SECURITY CHECK: MAC WHITELIST ----
  IPAddress clientIp = client.remoteIP();
  String clientMac = getMacFromIp(clientIp);
  Serial.print("Client IP: ");
  Serial.print(clientIp);
  if (clientMac.length() > 0) {
    Serial.print(", MAC: ");
    Serial.println(clientMac);
    if (!isMacAllowed(clientMac)) {
      Serial.println("!!! SECURITY ALERT: Client MAC not in whitelist. Disconnecting.");
      client.stop();
      return;
    } else {
      Serial.println("Client Authorized.");
    }
  } else {
    Serial.println(", MAC: Not found in ARP table yet. Warning only.");
    // First request from a new device often arrives before the ESP's ARP
    // table has cached its MAC. We let the request through and rely on the
    // next one being authenticated properly. For a stricter setup, uncomment
    // the next line so unknown devices are blocked outright.
    // client.stop(); return;
  // ---------------------------------------

  unsigned long requestStart = millis();
  while (!client.available() && millis() - requestStart < 2000) {
    delay(1);
  }

  if (!client.available()) {
    Serial.println("HTTP request timeout");
    client.stop();
    Serial.println("Client Disconnected.");
    return;
  }

  String requestLine = client.readStringUntil('\n');
  requestLine.trim();
  Serial.print("HTTP request: ");
  Serial.println(requestLine);

  // Only FORWARDS is gated by the LiDAR
  // the other directions are still allowed because they let the operator strafe or turn out of the obstacle.
  // STOP and BACKWARDS go straight through.
  if (requestLine.startsWith("GET /FORWARDS")) {
    if (stopTriggeredByLidar) {
      sendMotionCommand(0, 0, 0, "STOP", "LiDAR block");
    } else {
      sendMotionCommand(1, 0, 0, "FORWARDS");
    }
  } else if (requestLine.startsWith("GET /LEFT")) {
    sendMotionCommand(0, 1, 0, "LEFT");
  } else if (requestLine.startsWith("GET /RIGHT")) {
    sendMotionCommand(0, 0, 1, "RIGHT");
  } else if (requestLine.startsWith("GET /BACKWARDS")) {
    sendMotionCommand(1, 1, 1, "BACKWARDS");
  } else if (requestLine.startsWith("GET /STOP")) {
    sendMotionCommand(0, 0, 0, "STOP", "Web");
  }

  while (client.available()) {
    client.read();
  }

  serveControllerPage(client);
  delay(1);
  client.stop();
  Serial.println("Client Disconnected.");
}

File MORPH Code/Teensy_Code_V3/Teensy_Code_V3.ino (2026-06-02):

// Teensy 4.0 Robot Code 
#include <math.h>
#include <HardwareSerial.h>
#include <SoftwareSerial.h>
#include <ODriveUART.h> // ODrive v0.5.x ASCII UART interface
#include <Ramp.h>
#include <SerialTransfer.h>
#include "structdef.h"

// ---------------------------------------------------------
// WiFi / Communication Configuration START
// ---------------------------------------------------------
constexpr uint32_t WiFi_BAUD = 115200;
HardwareSerial& WiFi_serial = Serial7;
enum State { FIND_AA, FIND_55, READ_PAYLOAD, READ_SUM };
State comm_state = FIND_AA;
uint8_t payload[6];
int idx = 0;
uint8_t seq = 0;
// Control inputs from WiFi
int16_t wifi_a = 0;
int16_t wifi_b = 0;
int16_t wifi_c = 0;
// ---------------------------------------------------------
// WiFi / Communication Configuration END
// ---------------------------------------------------------

// ---------------------------------------------------------
// Robot Hardware and Tuning Configuration START
// ---------------------------------------------------------
// Printing with stream operator helper functions
template<class T> inline Print& operator <<(Print &obj,     T arg) { obj.print(arg);    return obj; }
template<>        inline Print& operator <<(Print &obj, float arg) { obj.print(arg, 4); return obj; }

HardwareSerial& odrive_serial1 = Serial5; 
HardwareSerial& odrive_serial2 = Serial6;
HardwareSerial& odrive_serial3 = Serial4;
HardwareSerial& odrive_serial4 = Serial1;
HardwareSerial& odrive_serial5 = Serial2; 
HardwareSerial& odrive_serial6 = Serial3;
// ODrive object initialization
// Leg index convention (matches structdef.h and gait tables): 0=FR, 1=BL, 2=FL, 3=BR
// Each leg ODrive controls two axes: axis0 and axis1 (hip and knee motors).
// Two shoulder ODrives each serve two legs (one axis per leg).
ODriveUART odrive1(odrive_serial1);  // ODrive 1 — Leg 0 FR (Serial5)
ODriveUART odrive2(odrive_serial2);  // ODrive 2 — Shoulder  BL(ax0) + BR(ax1) (Serial6)
ODriveUART odrive3(odrive_serial3);  // ODrive 3 — Leg 2 FL (Serial4)
ODriveUART odrive4(odrive_serial4);  // ODrive 4 — Leg 3 BR  (Serial1)
ODriveUART odrive5(odrive_serial5);  // ODrive 5 — Shoulder  FL(ax0) + FR(ax1) (Serial2)
ODriveUART odrive6(odrive_serial6);  // ODrive 6 — Leg 1 BL  (Serial3)


// UNUSED (testing purposes)
//matrix goes [FR, FL,BR,BL] - this matrix used to map the measured absolute encoder pos, can be put into code later
// double limitfrontintialPos[legn][coor] = {{ //axis 0 ext and axis 1comp
//   0.4987383484840393 ,  0.1413793563842 , 1. },  //leg x M0, legx M1, is shoulder postion(unused) 
//   {-1.25954151153564458, -0.3403044044971466 , 1. }, 
//   { -1.0587282180786133 ,   -0.8294696807861328 , 1. }, 
//   { 1.1962547302246094 ,  0.26903823018074036, 1.
// }};
// double limitbackintialPos[legn][coor] = {{//axis 0 comp axis 1 ext
//      -0.843109130859375 ,  -1.1795721054077148 , 1. },  //leg x M0, legx M1, is shoulder postion(unused) 
//   {  0.07016944885253906 , 0.9914951324462891 , 1. },
//   {0.2774391174316406 ,   0.5063495635986328 , 1. },
//   { -0.1145868375 ,  -1.0471487045288086 , 1.
// }};

// Motor Limits (Were initially 100)
float vellim = 100.0;
float accellim = 100.0;
float decellim = 100.0;
// Odrive Tuning Parameters
float posg = 100; //100
float velg = 0.3; //0.3
float velintg = 0.4; //0.4
float posgsh = 40.0; //shoulder
float velgsh = 0.08; //shoulder
float velintgsh = 0.2; //shoulder
// ---------------------------------------------------------
// Robot Hardware and Tuning Configuration END
// ---------------------------------------------------------

// Simulated packet items for compatibility with existing logic
// (Since the new WiFi packet only has 3 values, we need to decide how to map buttons)
int closedloopRequest = 0; // 1 = request IDLE, 2 = request closed-loop control
int stopRequest = 0; 
int moveEnableRequest = 0; 

// Gait Control Ratios
// set from WiFi commands, range typically -1.0 to +1.0
float LRrat;    // left-right strafe ratio. maps to 'b' in create_mat()
float FBrat;    // forward-backward ratio. maps to 'a' in create_mat()
float RTrat;    // yaw rotation ratio. maps to 'c' in create_mat()
float oldLRrat; // previous frame's value. used to detect command changes
float oldFBrat; // and trigger a gait matrix recompute when any ratio changes
float oldRTrat;
float ws_gain = 0.0; // weight shift gain: 0 = disabled, 1 = full centroid shift (~27mm lat, ~33mm fwd)
// Robot Physical Parameters
float leglen = 140.0;
float feetlen = 85.0;  
float hleg[4]      = { 280.0f, 280.0f, 280.0f, 280.0f };  
float hleg_base[4] = { 270.0f, 275.0f, 280.0f, 280.0f };  //  real measured physical standing height (mm) 
// Global Variables
int loop_timer = 13;  // 80ms base → ~200ms/phase at FBrat=1.0 (demand=1.0 → ×2.5), 3.2s full cycle
int citr; //current gait phase index (0-15)
int itrflag; //set to 1 when all 12 interpolations finish one phase
int closedloopflag;
int mode; //used first to set trap_traj (0 = standing, 1 = walking)
int offsetflag; //used in setup for finding motor postions in interpolation
int homeflag; //either 1 or 0 depending on leg at home pos (moves back to inipos when set to 1)
int itrchange; // when it has finished its (VARIABLE) point leg cycle in case it wants to change to a new gait
int modechange;//used to know when movement is called so it can assess wether a new gait is needed
int finishcount; //counts for all 4 legs and 3 coords (to 12) that myramp function is finished

long comm_millis; 
unsigned long currentmillis; 

double interpout [legn][coor];
double inipos[legn][coor];
double mat[legn][coor]; //inital gait matrix
double invmat[legn][coor];

// Gait Initialisation
gait_struct crawl;

// Function Prototypes
void state(int x);
void setInputMode(int mode); //added to set input mode to trap traj
void pos_est(double pos[legn][coor]);
void create_mat(double q[4][3],gait_struct *gait,float a,float b,float c,float ws,int iter);
void kinematics_mat(double inp[legn][coor], double out[legn][coor],double pos[legn][coor]);
void actuate(double inp[legn][coor]);
void actuate2();
void checkchange();
void modify_lim_gain();
void compute_offsets(float h, float &off1, float &off2);
void sendResponse(float, float, float);
void body_level_update(float terrain_pitch_deg, float terrain_roll_deg);
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

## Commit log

2026-06-02 Initial upload (CAD is missing)
    [ESPCode_V2.ino, Teensy_Code_V3.ino]
2026-06-02 Corrected Teensy code
2026-06-03 Create CAD
2026-06-03 All CAD
    [Clasplower.SLDPRT, Clasplower.STEP, Claspupper.SLDPRT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]
